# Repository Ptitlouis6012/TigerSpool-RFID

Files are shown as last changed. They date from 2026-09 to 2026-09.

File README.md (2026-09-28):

<p align="center">
  <picture>
    <source media="(prefers-color-scheme: dark)"  srcset="assets/logo-tigertag-head-dark.svg">
    <source media="(prefers-color-scheme: light)" srcset="assets/logo-tigertag-head.svg">
    TigerTag
  </picture>
</p>

<h1 align="center">TigerSpool RFID</h1>

<p align="center">
  <strong>Tap a spool on the box. The filament lands in the right printer slot.</strong><br>
  A 2.0" touchscreen, a PN532 reader, and no typing.
</p>

<p align="center">
  
  
  
  
  
</p>

<p align="center">
  <a href="https://tigertag-project.github.io/TigerSpool-RFID/">
    Install TigerSpool from your browser
  </a>
</p>

<p align="center">
  <a href="#what-it-is">What it is</a>
  &nbsp;&middot;&nbsp;
  <a href="#the-case-a-desktop-stand-or-built-into-your-printer">Print the case</a>
  &nbsp;&middot;&nbsp;
  <a href="#before-you-start">Before you start</a>
  &nbsp;&middot;&nbsp;
  <a href="#quick-start">Quick start</a>
  &nbsp;&middot;&nbsp;
  <a href="#build-it-yourself">Build one</a>
</p>

<p align="center">
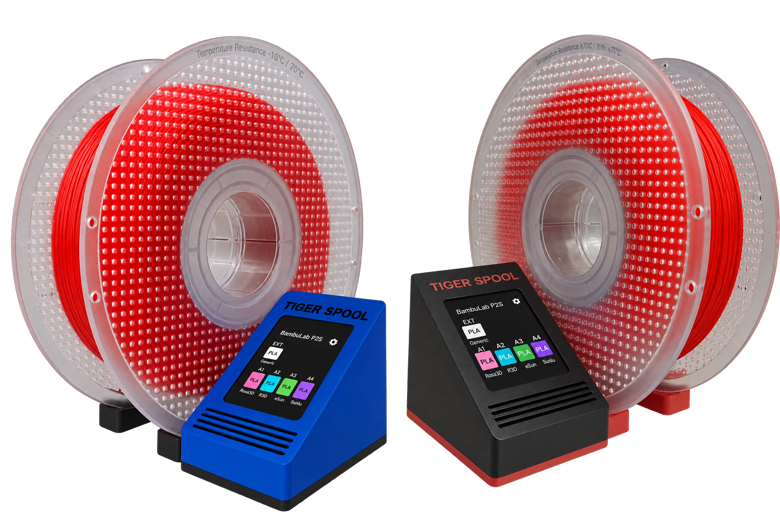
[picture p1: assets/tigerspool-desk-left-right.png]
Two TigerSpool desktop stands side by side: spool on the left, and spool on the right
  
</p>

---

**TigerSpool RFID** is open-source firmware for a small box that sits next to
your 3D printer. Hold a spool carrying a TigerTag NFC chip against it, pick a
slot on the touchscreen, and the box writes the filament into that slot on the
printer — material, brand, colour and temperatures. No app, no keyboard, no
retyping what the tag already knows.

MIT licensed. Built with PlatformIO for the ESP32-S3.

---

## What it is

Your printer already has a slot list. Your filament already carries its own
identity. TigerSpool is the thirty centimetres between them.

<p align="center">
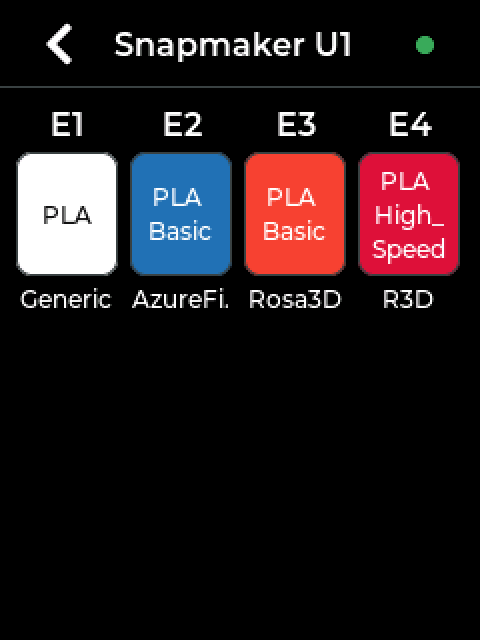
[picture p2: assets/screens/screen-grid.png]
A printer's slots on the TigerSpool screen
  
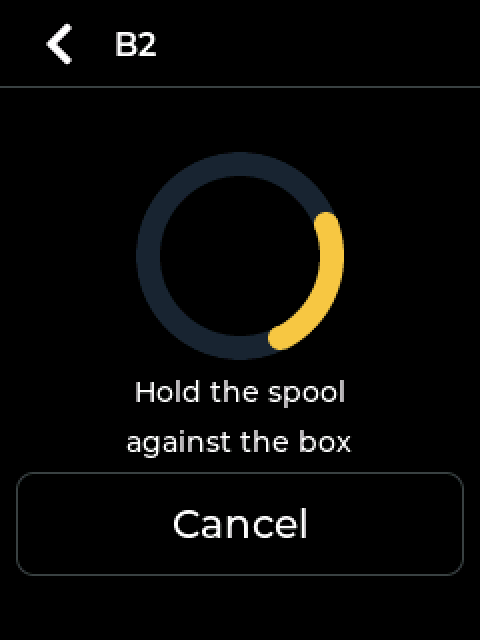
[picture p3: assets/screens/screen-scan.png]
Hold the spool against the box
  
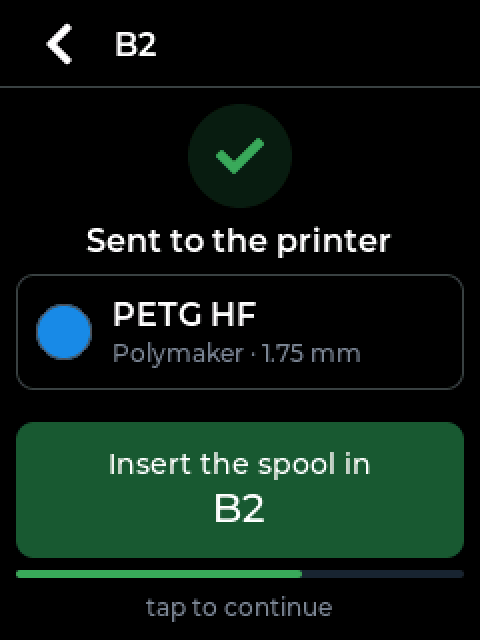
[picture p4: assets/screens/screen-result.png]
Sent to the printer: insert the spool in its slot
  
</p>

<p align="center">
  <sub>1. Tap a slot · 2. Hold the spool against the box · 3. Sent - load it where the box says.</sub>
</p>

- **Tap a slot, present the spool, done.** There is nothing to confirm: the
  assignment leaves for the printer as soon as the tag is read, over the
  printer's own protocol, and the box tells you which slot to load.
- **Scan mode: what is this spool?** Put one on the reader and the box shows
  what the chip holds - colour, material, brand, the two temperature windows,
  the drying instruction, what is left on it, and whether the tag is certified.
  No printer involved.
- **Your printers come from your account.** They are configured once, in Tiger
  Studio Manager, and every TigerSpool you own reads the same list.
- **It speaks nine languages** - English, French, German, Spanish, Italian,
  Polish, both Portuguese and Chinese - and asks which one before anything else.
- **It updates itself.** Over the air, verified, from this repository's releases.

## The case: a desktop stand, or built into your printer

**The desktop stand is TigerSpool.** It stands beside any printer, holds the
spool against the reader while you tap, and is the one to print if you are not
sure. It comes in two mirrored versions, the spool on the left of the screen or
on the right. No screws, no inserts: it is 100 % printed, and it prints without
supports.

<div align="center">

| Spool on the left | Spool on the right |
|---|---|
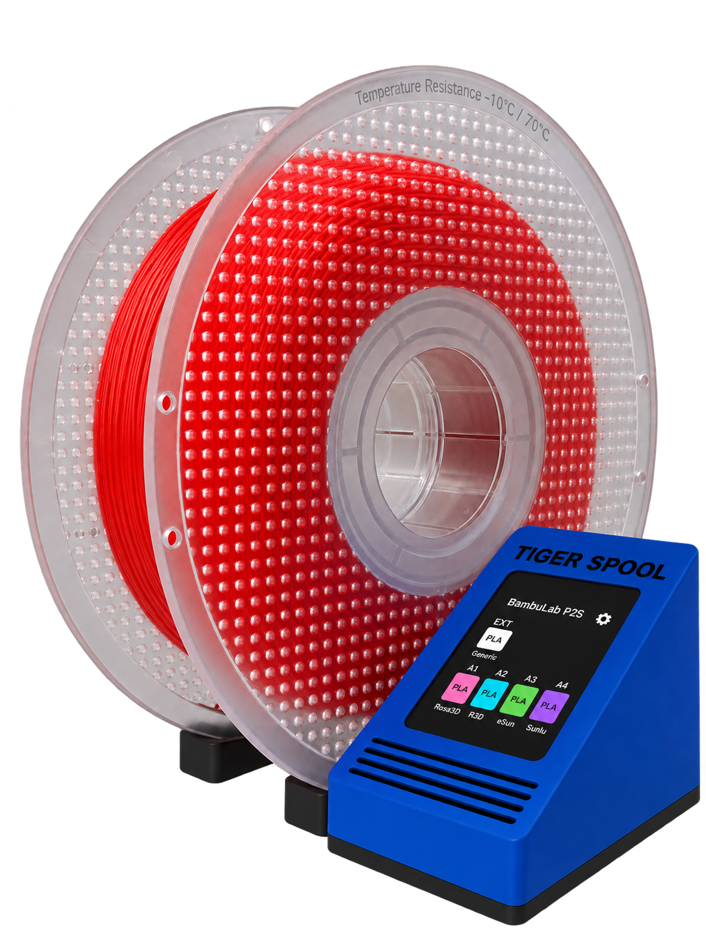
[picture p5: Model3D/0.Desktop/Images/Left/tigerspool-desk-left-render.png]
The desktop stand, spool on the left
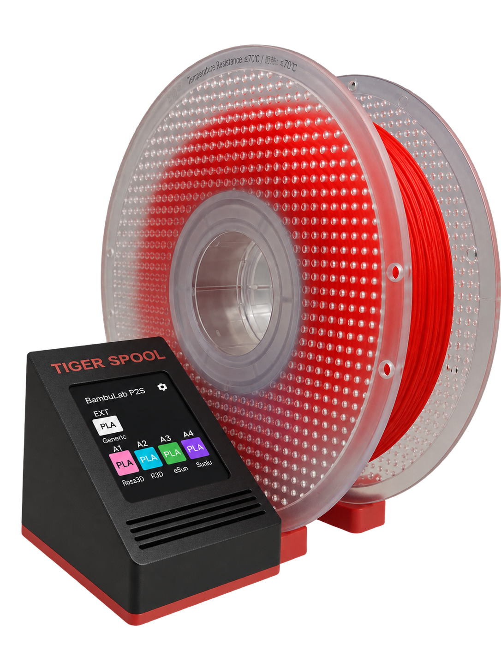
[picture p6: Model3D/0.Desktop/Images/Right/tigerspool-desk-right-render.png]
The desktop stand, spool on the right
|  |  |
| **[Print it from MakerWorld](https://makerworld.com/models/3360492-tigerspool-desktop-stand-spool-on-the-left)** · [files](Model3D/0.Desktop/) | **[Print it from MakerWorld](https://makerworld.com/models/3360619-tigerspool-desktop-stand-spool-on-the-right)** · [files](Model3D/0.Desktop/) |

</div>

**The printer integrations** are the same TigerSpool - same board, same reader,
same firmware - in a shell that clips onto a printer's own screen, so the box
lives where the spools are loaded.

<div align="center">

| Printer | | Print it |
|---|---|---|
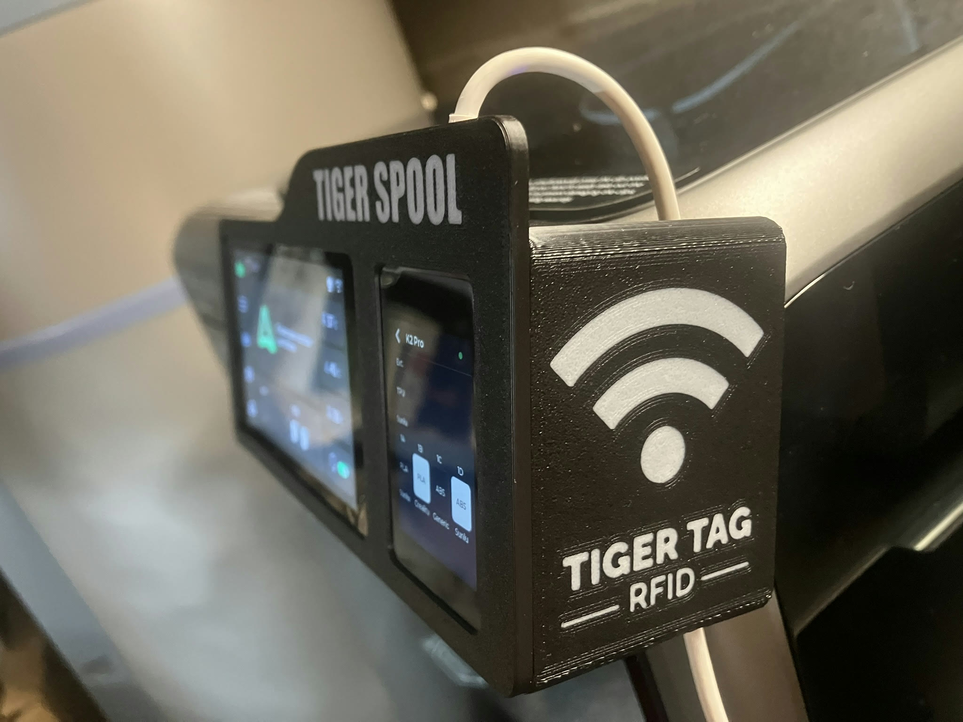
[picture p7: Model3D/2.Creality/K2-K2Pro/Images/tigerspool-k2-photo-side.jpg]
TigerSpool on a K2 Pro, the RFID reader and its logo on the side
| **Creality K2**<br>**Creality K2 Pro** |  | **[MakerWorld](https://makerworld.com/models/3361291-tigerspool-for-creality-k2-and-k2-pro)** · [files](Model3D/2.Creality/K2-K2Pro/) |
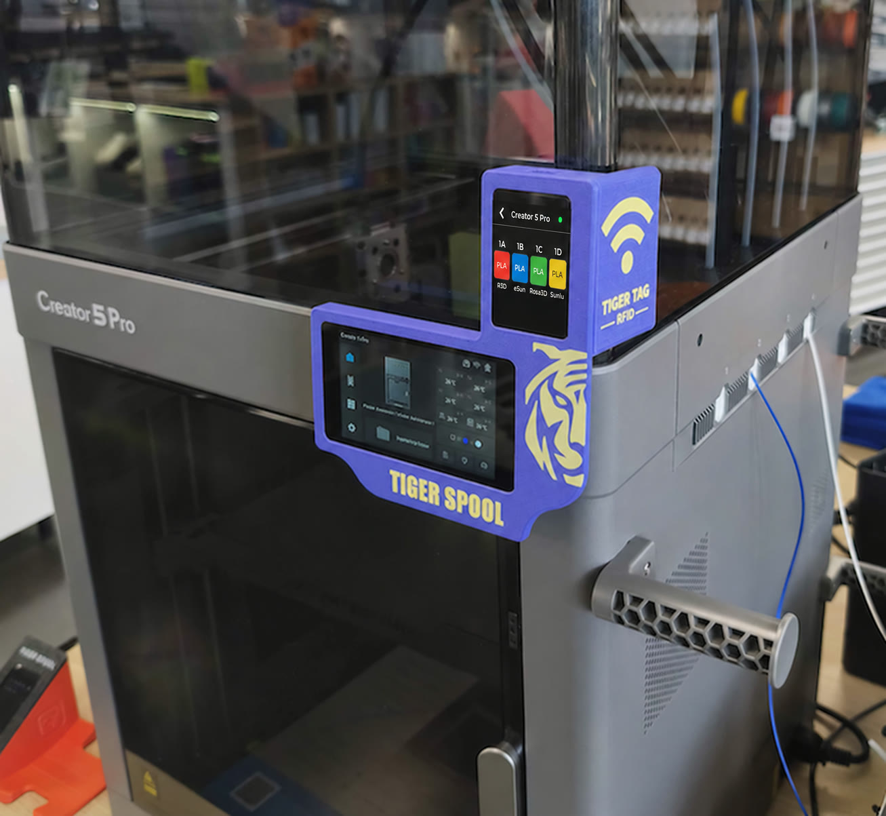
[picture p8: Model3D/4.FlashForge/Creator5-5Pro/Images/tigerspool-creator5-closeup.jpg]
TigerSpool clipped onto a Creator 5 Pro, its screen on and the RFID logo on the side
| **FlashForge Creator 5**<br>**FlashForge Creator 5 Pro** |  | **[MakerWorld](https://makerworld.com/models/3361301-tigerspool-rfid-for-flashforge-creator-5-and-5-pro)** · [files](Model3D/4.FlashForge/Creator5-5Pro/)<br><br>**[Firmware "FlashForge × TigerTag"](https://tigertag-project.github.io/FlashForge-TigerTag-Creator5-Firmware-Lan-and-Cloud/download/creator5/)**<br>LAN + Cloud<br>Recommended |
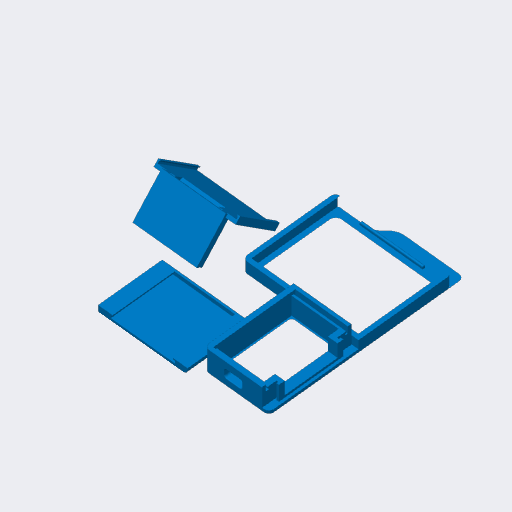
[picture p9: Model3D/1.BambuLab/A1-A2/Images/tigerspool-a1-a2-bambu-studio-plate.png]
The A1 and A2L case on the slicer plate
| **Bambu Lab A1**<br>**Bambu Lab A2L** |  | [files](Model3D/1.BambuLab/A1-A2/) - not on MakerWorld yet |
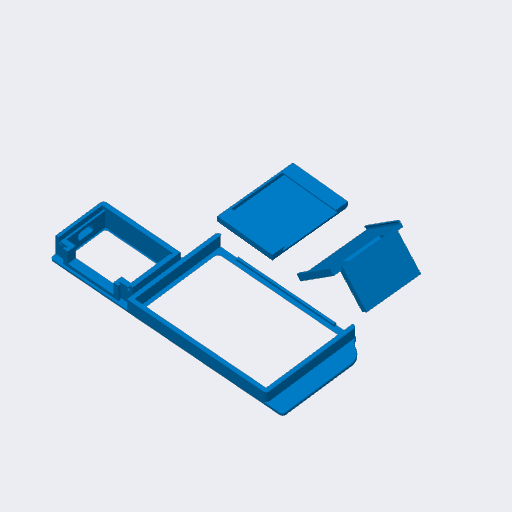
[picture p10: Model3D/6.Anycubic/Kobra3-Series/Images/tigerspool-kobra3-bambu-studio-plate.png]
The Kobra 3 case on the slicer plate
| **Anycubic Kobra 3**<br>**Anycubic Kobra 3 V2**<br>**Anycubic Kobra 3 Max**<br>**Anycubic Kobra 3 Max V2** |  | [files](Model3D/6.Anycubic/Kobra3-Series/) - not on MakerWorld yet |

</div>

Every model, its print settings and how to add one: **[Model3D/](Model3D/)**.

## Before you start

**This is the part that catches people out, so it is first.**

A TigerSpool has no keyboard and no way to type a printer's address, and that is
deliberate — it reads your printers from your TigerTag account instead. Which
means two things have to exist before the box is useful:

### 1. A TigerTag account, created in Tiger Studio Manager

**[Tiger Studio Manager](https://github.com/TigerTag-Project/TigerTag-Studio-Manager)**
is the desktop application for the ecosystem. Install it and create an account
there. That account is what the TigerSpool signs in to — by e-mail, or with
Google through a QR code, so you never type a password on a 2" screen.

Without an account, the box gets through Wi-Fi setup and then has nothing to
sign in to.

<p align="center">
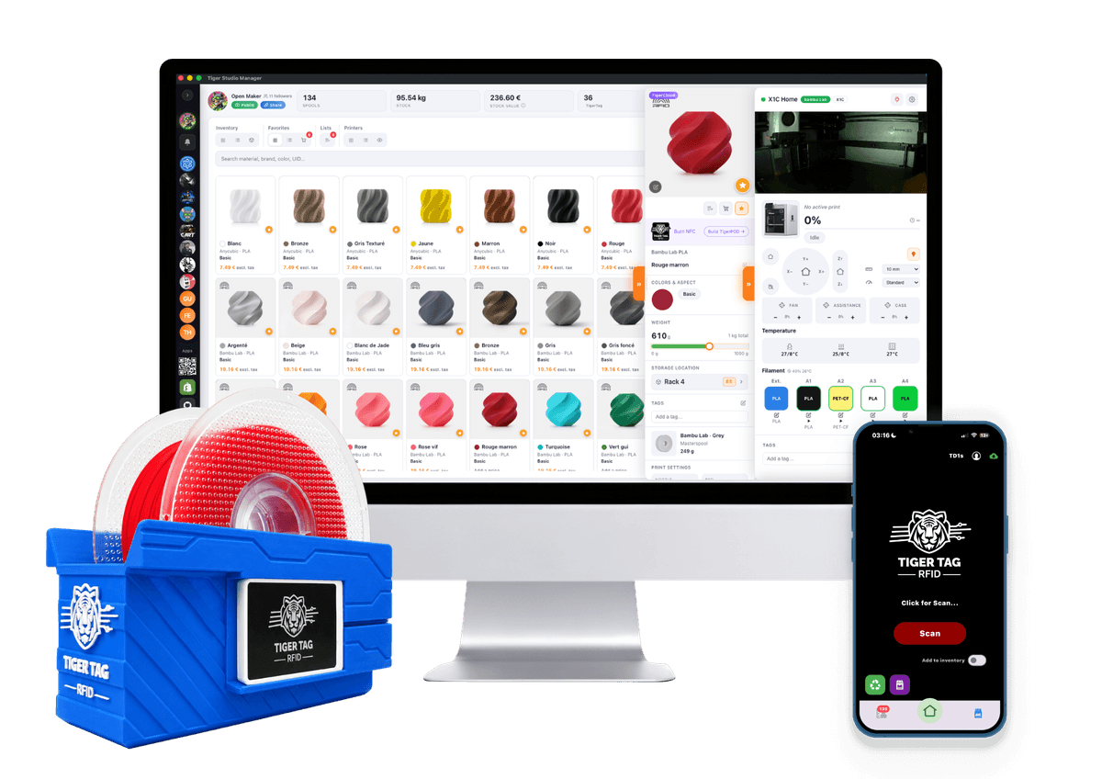
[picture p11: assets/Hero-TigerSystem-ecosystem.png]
The TigerTag system: a TigerPOD reader, Tiger Studio Manager on a desktop, and the TigerTag app on a phone
  
</p>

<p align="center">
  <sub>The TigerTag system: one account, shared by Tiger Studio Manager, the
  TigerTag app and every device - TigerSpool included.</sub>
</p>

### 2. Your printers, added in Tiger Studio Manager

Adding a printer means Tiger Studio finds it on your network, or you enter its
address and access code, and stores it against your account.

**If you have not done this, the printer list on the box will be empty.** That is
not a fault and there is nothing to fix on the device — it is showing you exactly
what your account contains. Add the printer in Tiger Studio, and it appears on
the box at the next sync.

The same is true for the details: the access code, the IP address, the brand and
model all come from there. TigerSpool reads that list; it does not build it.

<p align="center">
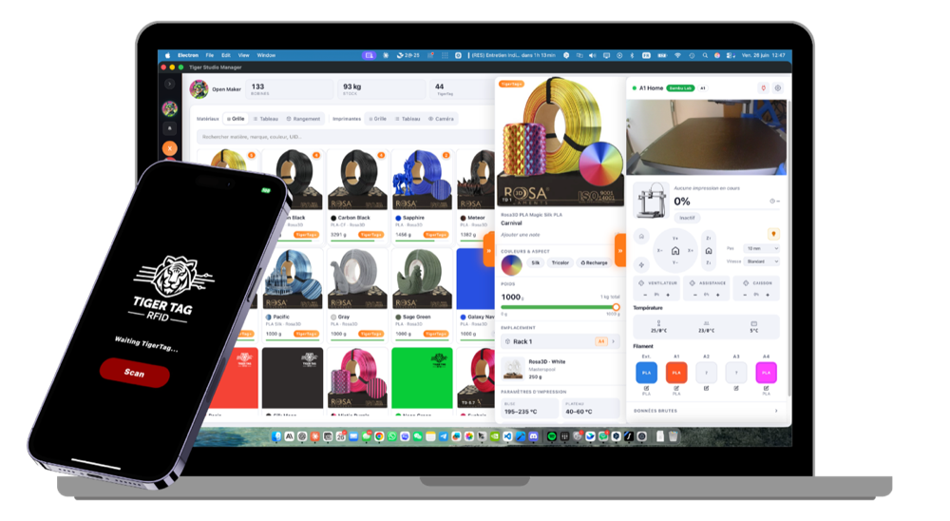
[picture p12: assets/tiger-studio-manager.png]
Tiger Studio Manager showing a filament library and a printer's slots
  
</p>

<p align="center">
  <sub>Tiger Studio Manager. Your filaments and your printers live here — the box
  reads this list, it does not build it.</sub>
</p>

> **In short:** Tiger Studio Manager → create an account → add your printers →
> *then* set up the box.

## Quick start

### Step 1 — install from your browser

**Plug the board into your computer → click Install → wait a minute.** Use the
button at the top of this page. It writes the bootloader, the partition table,
the boot selector and the firmware.

Chrome, Edge or Opera, on a desktop or laptop. Safari and Firefox do not
implement WebSerial and no mobile browser does — the page says so rather than
failing quietly.

### Step 2 — set it up on the box

1. **Pick your language.** Nine of them, before anything else.
2. **Join Wi-Fi.** The box shows a QR code. Scan it with your phone, and a page
   opens listing the networks it can see. Pick yours, type the password on your
   phone, and the box joins — no reboot, nothing typed on the small screen.
3. **Sign in.** E-mail and password, or Google through a second QR code.
4. **Your printers arrive.** From your account, as configured in Tiger Studio.
   The box's address on your network (`http://tigerspool-xxxx.local/`) shows
   who is signed in, lists those printers with a switch for each, syncs them
   again, and signs out - all from a phone.

<p align="center">
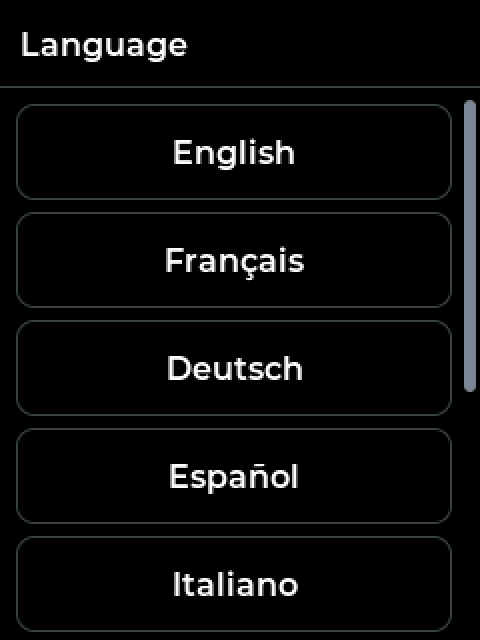
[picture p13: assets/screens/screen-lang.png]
Pick your language
  
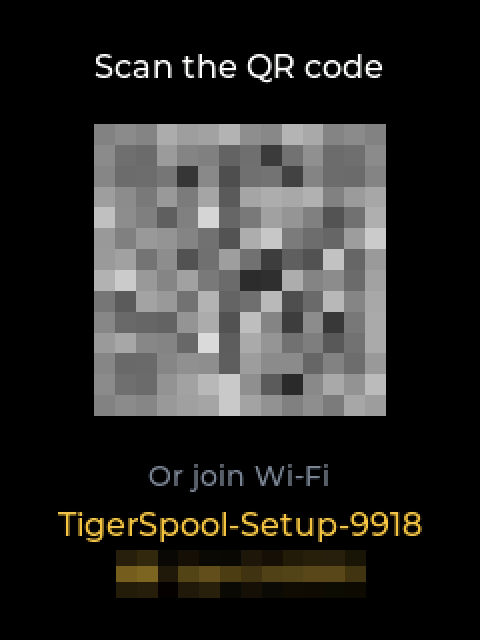
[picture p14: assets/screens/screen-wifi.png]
Join Wi-Fi from your phone by scanning a QR code
  
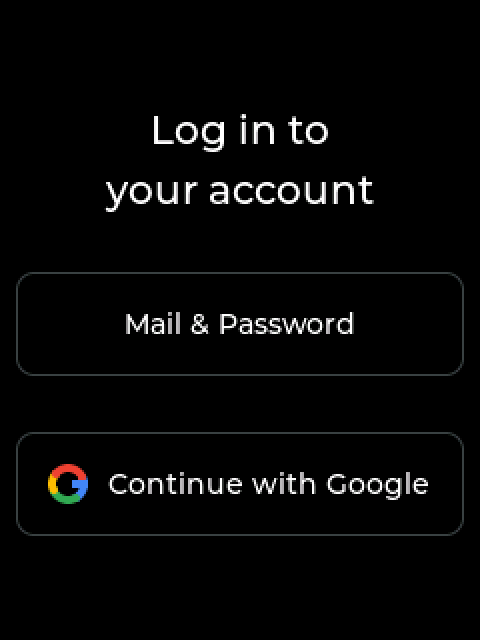
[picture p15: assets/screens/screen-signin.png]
Sign in to your TigerTag account
  
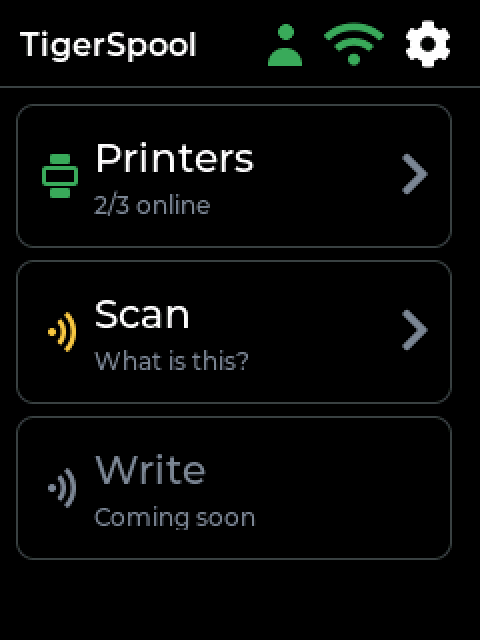
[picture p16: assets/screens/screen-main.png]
Ready: your printers, from your account
  
</p>

Then tap the slot you want and hold a tagged spool against the box. It is sent
to the printer as soon as it is read - there is nothing to confirm - and the
box then tells you where to put it.

That last part is the one people miss: **it tells the printer what the spool
is, it does not load it.** Putting the spool in that slot - the CFS, the AMS,
the ACE unit, whatever your printer calls its tray - is still yours to do.

From then on it updates itself over the air.

### Build it yourself

```bash
git clone https://github.com/TigerTag-Project/TigerSpool-RFID.git
cd TigerSpool-RFID

bash scripts/flash.sh --monitor
```

That builds the firmware, flashes it over USB and opens the serial console.
Requires [PlatformIO Core](https://docs.platformio.org/en/latest/core/installation/).

An ordinary flash **keeps your Wi-Fi credentials, your account session and your
printers** — nothing it writes touches the NVS partition. `--erase` wipes the
chip and is how you get a genuine first-boot again.

## Hardware

One board, one reader, four wires. The electronics are identical for every
printer brand — only the 3D-printed shell changes.

<div align="center">

| Qty | Component | Link |
|---|---|---|
| 1 | Waveshare ESP32-S3-Touch-LCD-2 — 240×320 IPS touch, ESP32-S3**R8**, 16 MB flash, 8 MB octal PSRAM. Screen, touch and MCU on one board | [buy](https://link.amazon/B06RoLfDi) |
| 1 | PN532 **V3** NFC module — DIP switches, set to **HSU (UART)**: both switches `0` / OFF, not I²C, not SPI | [buy](https://link.amazon/B0iJgHVtP) |
| 1 | USB-C to USB-A cable **that carries data** — a charge-only cable makes a working board look dead: no serial port ever appears | [buy](https://link.amazon/B00Xg3WT4) |
| — | Four jumper wires — 3V3, GND, TX, RX | ships with the PN532 |
| 1 | 3D-printed case — the desktop stand, or the integration made for your printer ([above](#the-case-a-desktop-stand-or-built-into-your-printer)) | [MakerWorld](https://makerworld.com/@TigerTag) · [Model3D/](Model3D/) |
| *opt.* | Magnetic USB connector — the port is the one part handled every day; the cable lets go instead of the socket | [buy](https://link.amazon/B0bWVIBa0) |
| *opt.* | 3.7 V 1000 mAh LiPo cell, PH1.25 — charged over USB, and the box runs from it with the cable out. Optional: declare it in **Settings › Battery**, since the board cannot detect it. **Check the polarity** | [buy](https://link.amazon/B0fL0jjf3) |

</div>

**About 40 €** in total, plus filament.

> Some of the links above are Amazon affiliate links: buying through them pays
> the project a small commission at no cost to you. Nothing on this list is
> chosen because it is affiliated — any equivalent module works.

Full parts list: **[hardware/BOM.md](hardware/BOM.md)** ·
Wiring: **[docs/WIRING.md](docs/WIRING.md)** and **[hardware/pinout.md](hardware/pinout.md)**

<p align="center">
  <a href="docs/WIRING.md">
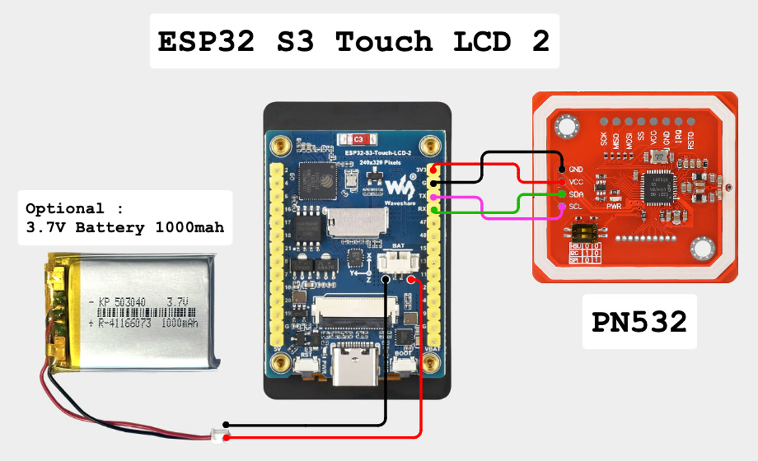
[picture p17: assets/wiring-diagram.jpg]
Wiring diagram: ESP32-S3-Touch-LCD-2 to PN532 — 3V3 to VCC, G to GND, TX to SCL, RX to SDA, and the optional 3.7 V battery on the BAT connector
    
  </a>
</p>
<p align="center">
  <sub><a href="https://app.cirkitdesigner.com/project/5b546f4e-70b8-4735-afff-be6bd36bc10c">Interactive schematic in Cirkit Designer</a></sub>
</p>

> **The reader goes on GPIO43/44.** Not GPIO6/7 — that pair is an I²C bus with
> pull-ups on this board. A PN532 wired there powers up, answers, and returns
> random UIDs with failing reads. It looks like a bad tag or a bad antenna. It is
> neither, and it costs a day. Follow [docs/WIRING.md](docs/WIRING.md) exactly.

## Printer support

**Every printer Tiger Studio Manager can add works with TigerSpool** - the
models below are that list. The current state of
every brand is in **[docs/PRINTER-COMPATIBILITY.md](docs/PRINTER-COMPATIBILITY.md)**,
which grades each on three levels — ✅ automatic, ⚙️ one setup step,
🧪 experimental. Read it before buying parts for a specific printer.

<div align="center">

| Brand | Firmware support | Transport |
|---|---|---|
| **Creality** | ✅ implemented, proven on hardware | WebSocket |
| **FlashForge** | ✅ implemented, proven on hardware | HTTP |
| **Bambu Lab** | ✅ implemented, proven on hardware - LAN and cloud mode | MQTT over TLS |
| **Snapmaker** | ✅ implemented, proven on hardware | Moonraker over WebSocket |
| **Elegoo** | ✅ implemented, reading proven on hardware | MQTT |
| **Anycubic** | ✅ implemented, proven on hardware - LAN and cloud mode | MQTT over TLS |

</div>

**How TigerSpool reaches each printer, and what to switch on first.** A
**Combo** is the same printer with its AMS, CFS, ACE or CANVAS attached, and
works the same way.

<div align="center">

| Printer | Mode | What to do on the printer |
|---|:---:|---|
| **Bambu Lab**<br>Bambu Lab A1 mini<br>Bambu Lab A1<br>Bambu Lab A2L<br>Bambu Lab P1P<br>Bambu Lab P1S<br>Bambu Lab P2S<br>Bambu Lab X1C<br>Bambu Lab X1E<br>Bambu Lab X2D<br>Bambu Lab H2D<br>Bambu Lab H2D Pro<br>Bambu Lab H2S<br>Bambu Lab H2C | LAN<br>Cloud, read only | LAN: turn on **LAN mode and Developer mode** on the printer. Cloud: nothing on the printer - the spools are shown, but a tag cannot be written to the slot. |
| **Creality**<br>Creality K1<br>Creality K1C<br>Creality K1 SE<br>Creality K1 Max<br>Creality K2<br>Creality K2 SE<br>Creality K2 Pro<br>Creality K2 Plus<br>Creality Hi<br>Creality Ender-3 V4<br>Creality SparkX i7 | LAN | Nothing: the printer accepts local requests while it stays on Creality Cloud. |
| **FlashForge**<br>FlashForge Creator 5<br>FlashForge Creator 5 Pro | LAN | Either turn **LAN mode** on - which disconnects FlashForge Cloud - or install the [FlashForge × TigerTag firmware](https://tigertag-project.github.io/FlashForge-TigerTag-Creator5-Firmware-Lan-and-Cloud/download/creator5/), which keeps LAN and Cloud on together. |
| **FlashForge**<br>FlashForge AD5X<br>FlashForge Adventurer 5M<br>FlashForge Adventurer 5M Pro<br>FlashForge A5 | LAN | Turn **LAN mode** on. It disconnects FlashForge Cloud. |
| **Anycubic**<br>Anycubic Kobra 3<br>Anycubic Kobra 3 V2<br>Anycubic Kobra 3 Max<br>Anycubic Kobra 3 Max V2<br>Anycubic Kobra S1<br>Anycubic Kobra X | LAN<br>Cloud | Your choice. **LAN mode**: pair the printer once in AnycubicSlicerNext - its credentials come from there, through Tiger Studio. **Anycubic Cloud**: add it to Tiger Studio in cloud mode; TigerSpool connects beside Tiger Studio without taking its place. |
| **Elegoo**<br>Elegoo Centauri 2<br>Elegoo Centauri 2 Combo<br>Elegoo Centauri Carbon 2<br>Elegoo Centauri Carbon 2 Combo | LAN | Nothing: the access code comes from your account. |
| **Snapmaker**<br>Snapmaker U1 | LAN | Nothing. |

</div>

A Bambu Lab printer in **cloud mode** is read-only: its spools are shown, but a
tag cannot be written to it - Bambu's cloud does not accept the command. Switch
the printer to LAN mode to write.

Slot names match the ones the printer and Tiger Studio use — `Ext.` plus
`1A`–`1D` on Creality and FlashForge, `A1`–`A4` then `B1`–`B4` on Bambu,
`E1`–`E4` on Snapmaker, `S1`–`S4` on Elegoo, `A1`–`A4` per ACE unit on
Anycubic. An Elegoo **Combo** has the CANVAS unit and its four colours,
`S1`–`S4`; a Centauri without it has the single `Ext.` slot. The table and its two traps are in the compatibility document.

## How many printers at once

**The limit is not a number of printers - it is how much memory their
connections take.** One TigerSpool has a fixed budget of **160 load slots**,
where one load slot is one kilobyte of the chip's internal RAM, and each printer
takes what its connection costs:

<div align="center">

| Printer | Load slots |
|---|---|
| First Bambu Lab in cloud mode | 50 |
| Each further Bambu Lab in cloud mode | 4 - they share one connection |
| Bambu Lab in LAN mode | 50 |
| Anycubic in LAN mode | 41 |
| First Anycubic in cloud mode | 50 |
| Each further Anycubic in cloud mode | 4 - they share one connection |
| Creality | 6 |
| Snapmaker | 5 |
| Elegoo | 3 |
| FlashForge | 2 |

</div>

The difference is encryption: a Bambu or an Anycubic talks over TLS, which is
what memory goes on; the others do not. So ten Elegoos fit where three LAN
Bambus do not.

**Settings > Printers** shows how full the budget is as a percentage. A printer
that would not fit is refused when you switch it on, with the reason on the
screen, rather than connecting and failing later. The measurements, the reasons
for 160, and what the budget does not account for are in
**[docs/CONNECTION-BUDGET.md](docs/CONNECTION-BUDGET.md)**.

## Documentation

<div align="center">

| | |
|---|---|
| [ARCHITECTURE.md](docs/ARCHITECTURE.md) | Layering, the state machine, why a backend knows nothing about the screen |
| [ONBOARDING.md](docs/ONBOARDING.md) | The first-boot journey, screen by screen |
| [WIFI-PROVISIONING.md](docs/WIFI-PROVISIONING.md) | The QR code and the captive portal |
| [ACCOUNT-PAIRING.md](docs/ACCOUNT-PAIRING.md) | E-mail and Google sign-in, and why RFC 8628 was rejected |
| [ACCOUNT-DATA.md](docs/ACCOUNT-DATA.md) | The shape a printer arrives in |
| [OTA.md](docs/OTA.md) | Partitions, the manifest, and what is settled before the first release |
| [PRINTER-COMPATIBILITY.md](docs/PRINTER-COMPATIBILITY.md) | Per-brand status and slot naming |
| [CONNECTION-BUDGET.md](docs/CONNECTION-BUDGET.md) | How many printers at once: load slots, every measurement behind them, why 160 |
| [PRESENCE.md](docs/PRESENCE.md) | How a box declares itself to the account, so Tiger Studio can list it |
| [WIRING.md](docs/WIRING.md) | The four wires |
| [ROADMAP.md](docs/ROADMAP.md) | What is deliberately not done yet, and what has to be decided first |

</div>

Contributors and agents start at **[AGENTS.md](AGENTS.md)** and
**[CODEMAP.md](CODEMAP.md)**.

## Known limitations

Written down rather than discovered.

- **The firmware is not signed.** Its update connection is verified against the
  root certificate store, so the box knows who it is talking to — but not who
  produced the image. The reasoning and the condition for changing that are in
  [docs/OTA.md](docs/OTA.md).
- **At most three printers that use TLS at once** - Bambu Lab in LAN mode and
  Anycubic, with every cloud Bambu on an account counting as one and every
  cloud Anycubic as one more. It is the
  chip's internal RAM, and the load budget enforces it; see
  [docs/CONNECTION-BUDGET.md](docs/CONNECTION-BUDGET.md). The two ways past it
  are in [docs/ROADMAP.md](docs/ROADMAP.md).
- **A battery has to be declared, in Settings.** The board has no way to tell
  whether a cell is on its connector - no sense line, and the two indirect
  signals were each measured wrong on real hardware - so it asks instead of
  guessing. Until someone answers, it reports no battery.
- **A printer is identified by its position in your account's list.** Reordering
  it in Tiger Studio can move a per-printer setting to the wrong machine. Tracked
  in [docs/reviews/](docs/reviews/).

## Part of the TigerTag ecosystem

TigerTag is an open NFC identification standard for 3D-printing materials. A
spool carries its own identity, and every device in the system reads the same
one.

- **[Tiger Studio Manager](https://github.com/TigerTag-Project/TigerTag-Studio-Manager)** — desktop printer and filament manager. **Start here**: it is where an account is created and printers are declared.
- **[TigerTag-RFID-Guide](https://github.com/TigerTag-Project/TigerTag-RFID-Guide)** — the protocol specification and public registry
- **[TigerSystem-Docs](https://github.com/TigerTag-Project/TigerSystem-Docs)** — ecosystem source of truth
- **[Tiger-Scale-V3](https://github.com/TigerTag-Project/Tiger-Scale-V3)** — the connected filament scale
- **[TigerPOD](https://github.com/TigerTag-Project/TigerPOD)** — open desktop NFC reader/writer
- **SDKs** — [Python](https://github.com/TigerTag-Project/TigerTag-SDK-Python) · [JavaScript](https://github.com/TigerTag-Project/TigerTag-SDK-JS)

## Contributing

Issues and pull requests are welcome. [CONTRIBUTING.md](CONTRIBUTING.md) has the
conventions; the short version is that `bash scripts/verify.sh` passes before
anything is reported as done, and everything committed is in English.

Security reports: [SECURITY.md](SECURITY.md).

## License

[MIT](LICENSE) — build it, sell it, fork it.

Third-party components keep their own licenses; see
[THIRD_PARTY_LICENSES.md](THIRD_PARTY_LICENSES.md). "TigerTag" and "TigerSpool"
are project names, not a license to imply endorsement — the terms for using them
on a product you sell are in [TRADEMARK.md](TRADEMARK.md).

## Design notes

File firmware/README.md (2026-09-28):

# firmware/

The TigerSpool firmware: one PlatformIO project for the Waveshare
ESP32-S3-Touch-LCD-2 with a PN532 reader. `tigerspool` is the build CI makes and
releases; `tigerspool-bench` is the same plus the diagnostics kept inside
`#if TIGERSPOOL_BENCH` (`src/bench.h`), and is never released.

## Layout

```
firmware/
├── platformio.ini          env: tigerspool
├── partitions.csv          two OTA slots, frozen - docs/OTA.md
├── include/                board and LVGL configuration, generated headers
│   ├── version.h           TIGERSPOOL_FW_VERSION, the one version macro
│   └── tigertag_db.h       generated from tools/tigertag_db - never hand-edited
├── lib/
│   └── PN532/              vendored reader driver - ONE copy, patches documented
├── tools/tigertag_db/      mirror of the public TigerTag reference tables
└── src/
    ├── main.cpp            the state machine and the only writable device state
    ├── printer.h           the backend interface and the printer record
    ├── printer_budget.h    how many printers at once - docs/CONNECTION-BUDGET.md
    ├── backend_*.cpp       one backend per brand, one object per printer
    ├── bambu_cloud.cpp     the TLS session every cloud Bambu on an account shares
    ├── filament_resolve.cpp what a slot is sent, field by field - pure, host-testable
    ├── product_api.cpp     the TigerTag+ product lookup, on its own task
    ├── reader.cpp          PN532 use, TigerTag decoding
    ├── battery.cpp         the cell on the boards that have one - GPIO5
    ├── tigertag_cloud.cpp  account sign-in, pairing, printer import
    ├── tt_db.cpp           reference-table lookups, compiled and downloaded
    ├── webcfg.cpp          captive portal, LAN page, /screen.bmp, /api/*
    ├── i18n.cpp            every on-screen string, in nine languages
    ├── net/                captive DNS, OTA, TLS helpers
    └── ui/                 LVGL screens, theme, icons, generated fonts
```

What each file owns, what it must not be asked to do, and the landmines to read
before editing it are in [../CODEMAP.md](../CODEMAP.md). This tree is the
overview; the map is the reference.

## Rules for this tree

**No credentials, ever.** Not Wi-Fi, not printer access codes, not API keys with
authority. Everything comes from NVS at runtime. The published binary is the same
for every user. See [../SECURITY.md](../SECURITY.md).

**One copy of the vendored library.** The prototype carries three, which have
already drifted into different behaviour —
[../docs/MIGRATION.md](../docs/MIGRATION.md#the-vendored-pn532-library). Patches
to a vendored library carry a comment saying what breaks without them.

**English only.** Comments, identifiers, log messages, commit messages.
User-facing strings go through the i18n layer (`i18n.cpp`), in every language
at once.

**Hardware facts get a comment explaining why.** Every constant that looks
arbitrary — a delay, a page range, a retry count — is arbitrary-looking because
it was expensive to find. Say what breaks if it changes.

## Build

```bash
pio run -e tigerspool                 # compile
bash ../scripts/flash.sh --monitor    # build, flash over USB, open the console
bash ../scripts/verify.sh             # the guards CI runs, plus a build
```

`flash.sh` checks the board's MAC before writing, so it cannot flash the wrong
device on a bench with several plugged in.

Most users will never do this — they install from the browser, and after that
the device updates itself over the air ([../docs/OTA.md](../docs/OTA.md)).

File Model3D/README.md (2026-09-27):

# 3D-printable cases

**The [desktop stand](0.Desktop/) is the base model.** It stands beside any
printer, and it is the one to print if you are not sure. Every other model is a
**printer integration**: the same TigerSpool in a shell that clips onto one
printer's own screen.

<p align="center">
  The desktop stand, spool on the left and spool on the right
</p>

| Model | Kind | MakerWorld | Files |
|---|---|---|---|
| Desktop stand, spool on the left | base, any printer | [print it](https://makerworld.com/models/3360492-tigerspool-desktop-stand-spool-on-the-left) | [`0.Desktop/`](0.Desktop/) |
| Desktop stand, spool on the right | base, any printer | [print it](https://makerworld.com/models/3360619-tigerspool-desktop-stand-spool-on-the-right) | [`0.Desktop/`](0.Desktop/) |
| Creality K2, K2 Pro | integration, clips onto the screen | [print it](https://makerworld.com/models/3361291-tigerspool-for-creality-k2-and-k2-pro) | [`2.Creality/K2-K2Pro/`](2.Creality/K2-K2Pro/) |
| FlashForge Creator 5, 5 Pro | integration, clips onto the screen | [print it](https://makerworld.com/models/3361301-tigerspool-rfid-for-flashforge-creator-5-and-5-pro) | [`4.FlashForge/Creator5-5Pro/`](4.FlashForge/Creator5-5Pro/) |
| Bambu Lab A1, A2L | integration, clips onto the screen | not yet | [`1.BambuLab/A1-A2/`](1.BambuLab/A1-A2/) |
| Anycubic Kobra 3, every model | integration, clips onto the screen | not yet | [`6.Anycubic/Kobra3-Series/`](6.Anycubic/Kobra3-Series/) |

Each brand directory lists its models. On MakerWorld every page carries the
full Bambu Studio project and the whole build guide; the bare parts, the other
slicers' projects and the Fusion sources are here.

---

## The rule that governs every model in this directory

**Only the shell changes. The electronics, the wiring and the connectors are
strictly identical across every model.**

Same Waveshare ESP32-S3-Touch-LCD-2. Same PN532. Same four wires on the same pins.
Same USB-C entry. A TigerSpool built for a Bambu Lab and one built for a Creality
are the same device in a different jacket, and either firmware image runs on
either one.

This is not a convention. It is what makes the project shippable:

- **One firmware.** No per-model build, no variant to pick in the installer, no
  way to flash the wrong image.
- **One bill of materials.** [../hardware/BOM.md](../hardware/BOM.md) is complete
  for every model.
- **One set of wiring instructions.** [../docs/WIRING.md](../docs/WIRING.md)
  is correct for every model.
- **Anyone can add a model** without touching a line of code.

A design that needs a different board, a different reader, extra components, or a
change to the pinout **is not a TigerSpool model**. It is a fork, and it is
welcome as one — under a different name.

---

## What each model has to do

Different only in how it mounts. Every one of them has to:

| Requirement | Why |
|---|---|
| Hold the PN532 antenna **2–4 cm** from where a spool naturally rests | That is the reader's entire range ([../docs/WIRING.md](../docs/WIRING.md)) |
| Keep the antenna **away from the display's metal back** and any ground plane | Both destroy what little range there is |
| Present the 2.0" screen at a readable, tappable angle | It is a touchscreen, used standing up |
| Leave the USB-C port reachable | Power, and recovery flashing |
| Print without supports where possible, and on a printer of the brand it is for | It is a case for that printer; it should print on it |
| Say clearly **where to hold the spool** | Moulded, embossed, or an obvious surface — not in a manual |

---

## Directory layout

```
Model3D/
├── TEMPLATE.md                the README every model starts from
├── 0.Desktop/                 free-standing, fits any printer - the universal one
├── 1.BambuLab/                one numbered directory per brand ...
│   ├── README.md              ... listing its models
│   └── X1C/                   ... and one directory per printer model
├── 2.Creality/
├── 3.Snapmaker/
├── 4.FlashForge/
├── 5.Elegoo/
└── 6.Anycubic/
```

Two levels, and only two: **brand, then printer model.** A case that fits a
whole range goes in the brand directory under the name of that range (`P1/`
for the P1P and the P1S); one that fits a single machine takes that machine's
name (`K2-Plus/`). A model that fits every printer is not a brand model at all:
it belongs in `0.Desktop/`, or next to it.

**A directory here is about physical mounting, not firmware support.** A case
can be designed for a printer before its network protocol works, so a directory
existing says nothing about whether the device talks to that printer.
[../docs/PRINTER-COMPATIBILITY.md](../docs/PRINTER-COMPATIBILITY.md) is the
authority on what actually works.

### What goes in a model directory

```
K2-Plus/
├── README.md                  from ../TEMPLATE.md
├── Images/                    what it looks like - a photo beats a render
├── Source/                    the editable design: .step, .f3d
├── OriginalFiles/             the parts as exported, one file each, no slicer settings
├── BambuStudio/               one directory per slicer the project is saved from
│   └── *.3mf
└── CrealityPrint/
    └── *.3mf
```

| What | Why |
|---|---|
| `README.md` | Which printers it fits, what to print and in what, how it goes together |
| `Images/` | Nobody downloads a case they cannot see. The slicer's own previews can be taken out of a 3MF (`Metadata/plate_1.png`, `top_1.png`) until there is a photo |
| `Source/` | So the next person can adapt it instead of starting again. `.step` opens everywhere; a native file (`.f3d`) is welcome beside it |
| `OriginalFiles/` | The bare parts, for any slicer and any printer |
| `<Slicer>/*.3mf` | A 3MF saved from a slicer carries the orientation, the supports and the plate for that slicer's printers, and is tied to it. One directory per slicer: `BambuStudio/`, `CrealityPrint/`, `OrcaSlicer/`, `PrusaSlicer/` |

Variants of one design (the desktop stand with the spool on the left or on the
right) are told apart by the file name, or by a `Left/` and `Right/` level where
there are several files per variant.

### Names

**Directories** are written to be read: capitals where they help (`BambuStudio`,
`OriginalFiles`, `K2-Plus`), a number in front of the top-level ones to set
their order. **Files** are lower case with hyphens:
`tigerspool-<model>-<variant>-<part>.3mf`, for example
`tigerspool-desk-left-display-cover.3mf`. **No spaces anywhere**: a space breaks
every link to the path in a README. `scripts/check-models.py` enforces all
three.

### Before a photo is committed

A phone photo records the phone, the time and **the GPS position it was taken
at**. Publish a copy with none of it, scaled to something a page can load:

```bash
ffmpeg -i IMG_1234.jpeg -vf "scale='min(2000,iw)':-2" -map_metadata -1 -q:v 3 \
    Model3D/<Brand>/<Model>/Images/tigerspool-<model>-photo-<view>.jpg
```

`-map_metadata -1` drops the metadata; ffmpeg applies the phone's rotation to
the pixels first, so the picture stays the right way up. Look at the
background too: a photo on a desk shows whatever else is on that desk.
`verify.sh` refuses a picture that still carries EXIF.

### Before a 3MF is committed

A slicer project records more than geometry. It keeps the **full path** of the
file each object was imported from - a user name and a folder layout, on a
public repository - and every object's name as the designer typed it.

```bash
python3 scripts/clean-3mf.py Model3D/<Brand>/<Model>/<Slicer>/*.3mf
```

cuts every source path down to its file name and prints every object name, so
you read them before anyone else does. `verify.sh` refuses a 3MF that still
carries a path.

## Contributing a model

1. Read the rule at the top. If your design needs different electronics, it is a
   fork, not a model.
2. **Print it and build one.** Fit, screen angle and read distance are not
   things a render tells you.
3. **Measure the read distance through the shell.** A case that pushes the
   antenna past ~4 cm produces a device that looks fine and reads nothing.
4. Copy [TEMPLATE.md](TEMPLATE.md) to your directory as `README.md` and fill
   it in: print settings, a photo, which printers it fits.
5. Include the editable source (`.step`, and the native file if you have one)
   so the next person can adapt it.
6. Run `scripts/clean-3mf.py` on your projects, then `bash scripts/verify.sh --quick`.
7. Add a row to the brand's README, and open a PR. See [../CONTRIBUTING.md](../CONTRIBUTING.md).

A model that has been printed and used beats a model that has been designed.

---

## Licensing

Model files contributed here are MIT-licensed like the rest of the repository
([../LICENSE](../LICENSE)). Do not contribute geometry derived from a
manufacturer's proprietary CAD, or from a model whose own license does not permit
redistribution.

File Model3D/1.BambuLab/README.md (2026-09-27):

# Bambu Lab

Cases that mount a TigerSpool on a Bambu Lab printer, one directory per printer
model. The rules every model follows, and the layout inside a model directory,
are in [../README.md](../README.md); a new model starts from
[../TEMPLATE.md](../TEMPLATE.md).

Until one fits your printer, the [desktop stand](../0.Desktop/) works beside any
of them.

| Model | Fits | Directory |
|---|---|---|
| [A1 and A2L](A1-A2/) | Bambu Lab A1, A2L - clips onto the screen | `A1-A2/` |

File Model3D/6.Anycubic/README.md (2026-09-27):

# Anycubic

Cases that mount a TigerSpool on a Anycubic printer, one directory per printer
model. The rules every model follows, and the layout inside a model directory,
are in [../README.md](../README.md); a new model starts from
[../TEMPLATE.md](../TEMPLATE.md).

Until one fits your printer, the [desktop stand](../0.Desktop/) works beside any
of them.

| Model | Fits | Directory |
|---|---|---|
| [Kobra 3 series](Kobra3-Series/) | Anycubic Kobra 3, Kobra 3 V2, Kobra 3 Max, Kobra 3 Max V2 - clips onto the screen | `Kobra3-Series/` |

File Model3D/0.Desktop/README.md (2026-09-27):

# Desktop stand

| Spool on the left | Spool on the right |
|---|---|
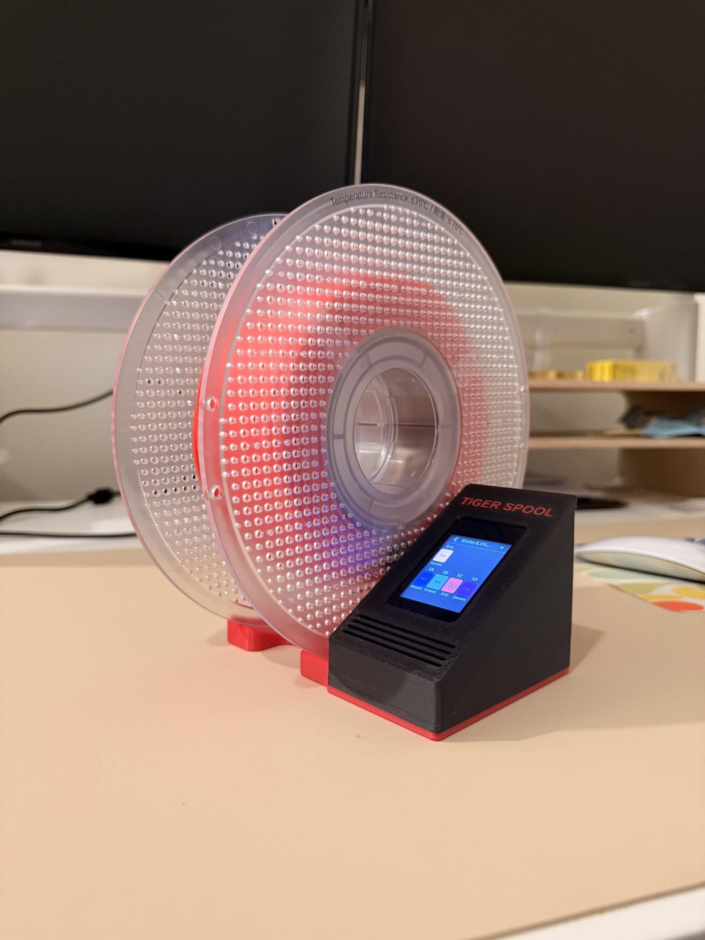
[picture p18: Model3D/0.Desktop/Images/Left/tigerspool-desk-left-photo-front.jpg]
The desktop stand, spool on the left
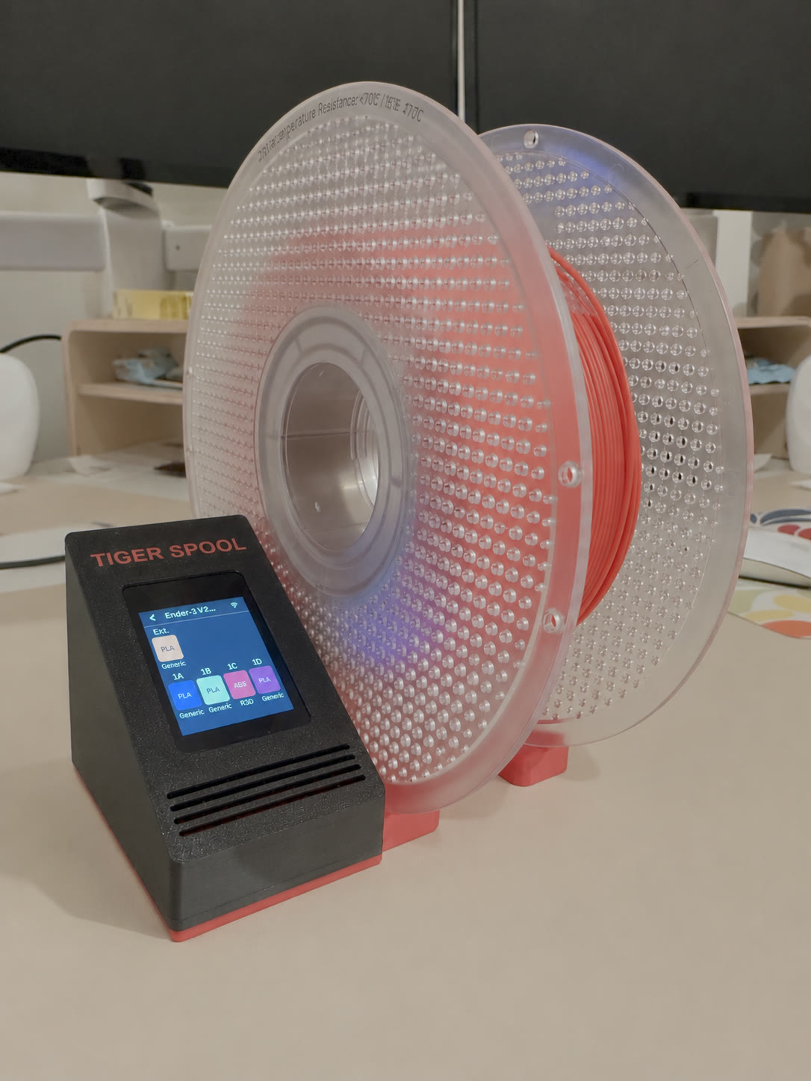
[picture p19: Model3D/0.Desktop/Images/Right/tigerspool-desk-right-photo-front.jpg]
The desktop stand, spool on the right
|  |  |
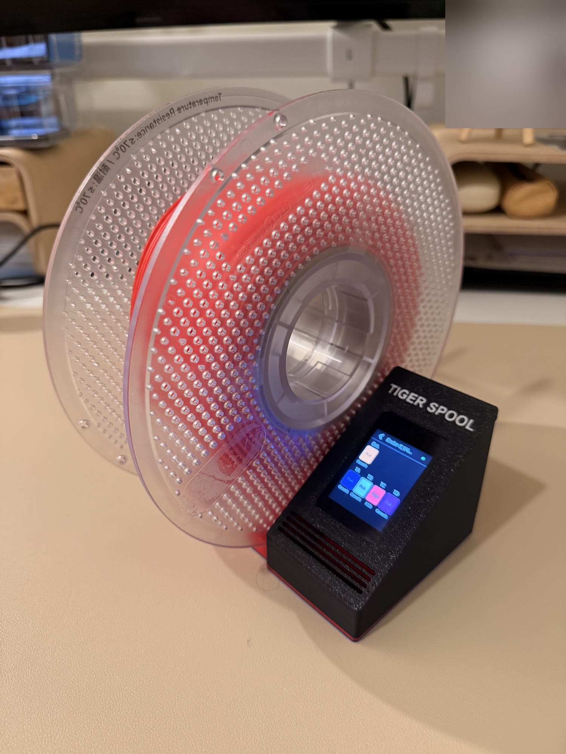
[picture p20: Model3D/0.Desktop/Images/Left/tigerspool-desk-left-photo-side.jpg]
Spool on the left, from the side
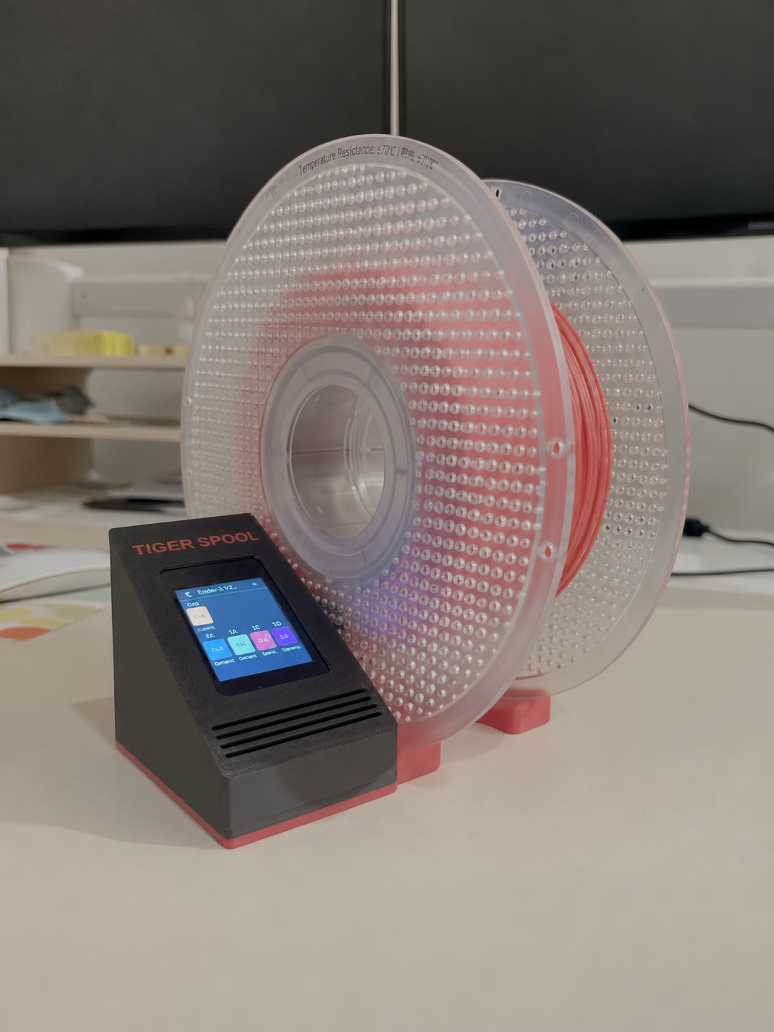
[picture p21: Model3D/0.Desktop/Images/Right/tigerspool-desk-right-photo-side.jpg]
Spool on the right, from the side
|  |  |

**Print it from MakerWorld:**
[spool on the left](https://makerworld.com/models/3360492-tigerspool-desktop-stand-spool-on-the-left) ·
[spool on the right](https://makerworld.com/models/3360619-tigerspool-desktop-stand-spool-on-the-right)

A free-standing stand for the bench or the desk. It is not attached to any
printer, so it fits every one of them - the base TigerSpool, which the
[printer integrations](../README.md) build on.

The stand with a spool resting against the reader

It comes in two mirrored versions: the spool rests **on the left** of the
screen, or **on the right**. Pick the one that suits where it sits.

## Files

Each version is three parts - the base, the display and the display cover.

| | Spool on the left | Spool on the right |
|---|---|---|
| Bambu Studio, every part on one plate | [`tigerspool-desk-left-full.3mf`](BambuStudio/tigerspool-desk-left-full.3mf) | [`tigerspool-desk-right-full.3mf`](BambuStudio/tigerspool-desk-right-full.3mf) |
| Creality Print, every part on one plate | [`tigerspool-desk-left-full.3mf`](CrealityPrint/tigerspool-desk-left-full.3mf) | [`tigerspool-desk-right-full.3mf`](CrealityPrint/tigerspool-desk-right-full.3mf) |
| Base, bare part | [`tigerspool-desk-left-base.3mf`](OriginalFiles/Left/tigerspool-desk-left-base.3mf) | [`tigerspool-desk-right-base.3mf`](OriginalFiles/Right/tigerspool-desk-right-base.3mf) |
| Display, bare part | [`tigerspool-desk-left-display.3mf`](OriginalFiles/Left/tigerspool-desk-left-display.3mf) | [`tigerspool-desk-right-display.3mf`](OriginalFiles/Right/tigerspool-desk-right-display.3mf) |
| Display cover, bare part | [`tigerspool-desk-left-display-cover.3mf`](OriginalFiles/Left/tigerspool-desk-left-display-cover.3mf) | [`tigerspool-desk-right-display-cover.3mf`](OriginalFiles/Right/tigerspool-desk-right-display-cover.3mf) |

The slicer projects carry the orientation, the supports and the settings below.
The bare parts carry geometry only, for any other slicer.

## Assembly

No screws, no inserts, no hardware to buy for the case: it is 100 % 3D
printed. The board and the reader go into the printed parts, and the parts
assemble on their own. Every part is designed to print without supports.

## Print settings

PLA, 0.4 mm nozzle and 15 % infill everywhere. The rest is what each project
was saved with:

| Project | Printer | Layer | Walls | Supports |
|---|---|---|---|---|
| Bambu Studio, left | A1 mini | 0.20 mm | 2 | none |
| Bambu Studio, right | A1 mini | 0.20 mm | 3 | none |
| Creality Print, left | Hi | 0.24 mm | 2 | none |
| Creality Print, right | K2 Pro | 0.20 mm | 3 | tree, painted on where needed |

The display part uses a second PLA colour for its details; the projects assign
it already. Print it in one colour and it still works.

## The parts

| Spool on the left | Spool on the right |
|---|---|
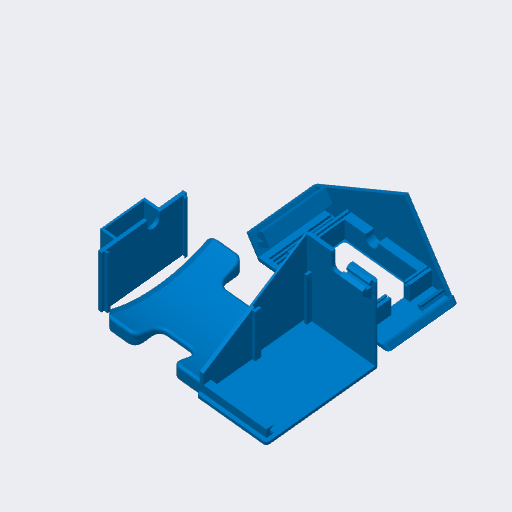
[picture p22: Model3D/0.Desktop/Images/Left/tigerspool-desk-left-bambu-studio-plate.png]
Plate, spool on the left
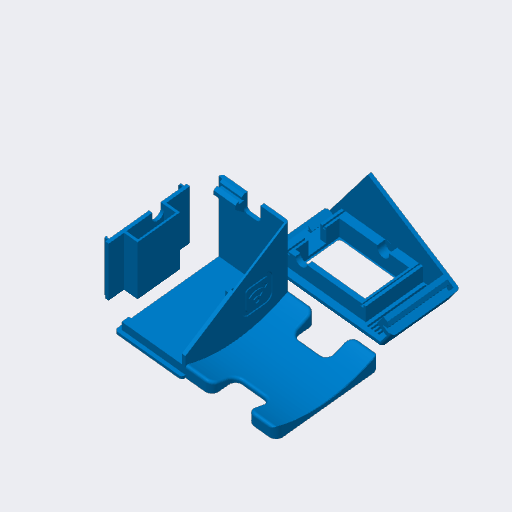
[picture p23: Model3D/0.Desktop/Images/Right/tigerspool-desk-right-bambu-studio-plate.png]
Plate, spool on the right
|  |  |

### From above

| Spool on the left | Spool on the right |
|---|---|
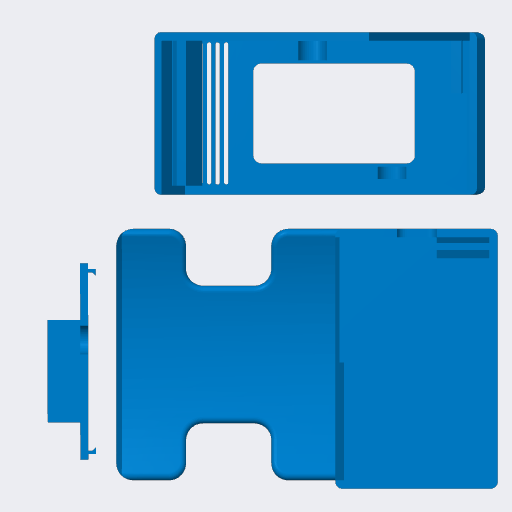
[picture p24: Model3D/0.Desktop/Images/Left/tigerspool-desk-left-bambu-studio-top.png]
Plate from above, spool on the left
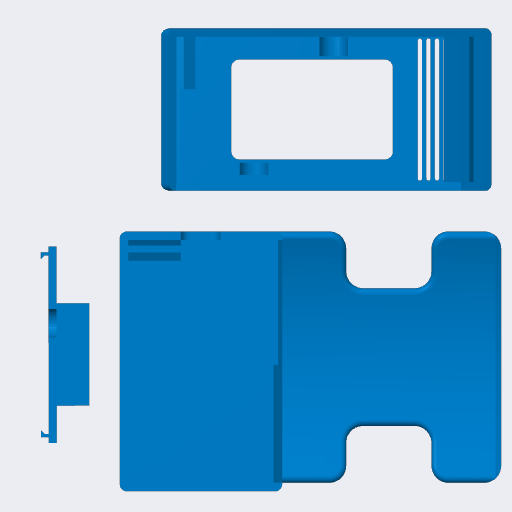
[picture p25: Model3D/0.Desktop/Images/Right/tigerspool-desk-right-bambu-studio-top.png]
Plate from above, spool on the right
|  |  |

The plate pictures are the slicers' own previews, taken out of the projects;
the Creality Print ones and a render of each version are in [`Images/Left/`](Images/Left/) and [`Images/Right/`](Images/Right/) too.

## Source

[`Source/tigerspool-desk.f3d`](Source/tigerspool-desk.f3d) - the Fusion design
both versions come from.

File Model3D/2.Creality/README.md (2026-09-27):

# Creality

Cases that mount a TigerSpool on a Creality printer, one directory per printer
model. The rules every model follows, and the layout inside a model directory,
are in [../README.md](../README.md); a new model starts from
[../TEMPLATE.md](../TEMPLATE.md).

Until one fits your printer, the [desktop stand](../0.Desktop/) works beside any
of them.

| Model | Fits | MakerWorld | Directory |
|---|---|---|---|
| [K2 and K2 Pro](K2-K2Pro/) | Creality K2, K2 Pro - clips onto the screen | [print it](https://makerworld.com/models/3361291-tigerspool-for-creality-k2-and-k2-pro) | `K2-K2Pro/` |

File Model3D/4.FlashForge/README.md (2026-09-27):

# FlashForge

Cases that mount a TigerSpool on a FlashForge printer, one directory per printer
model. The rules every model follows, and the layout inside a model directory,
are in [../README.md](../README.md); a new model starts from
[../TEMPLATE.md](../TEMPLATE.md).

Until one fits your printer, the [desktop stand](../0.Desktop/) works beside any
of them.

| Model | Fits | MakerWorld | Directory |
|---|---|---|---|
| [Creator 5 and Creator 5 Pro](Creator5-5Pro/) | FlashForge Creator 5, Creator 5 Pro - clips onto the screen | [print it](https://makerworld.com/models/3361301-tigerspool-rfid-for-flashforge-creator-5-and-5-pro) | `Creator5-5Pro/` |

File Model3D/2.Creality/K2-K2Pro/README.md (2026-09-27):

# Creality K2 and K2 Pro

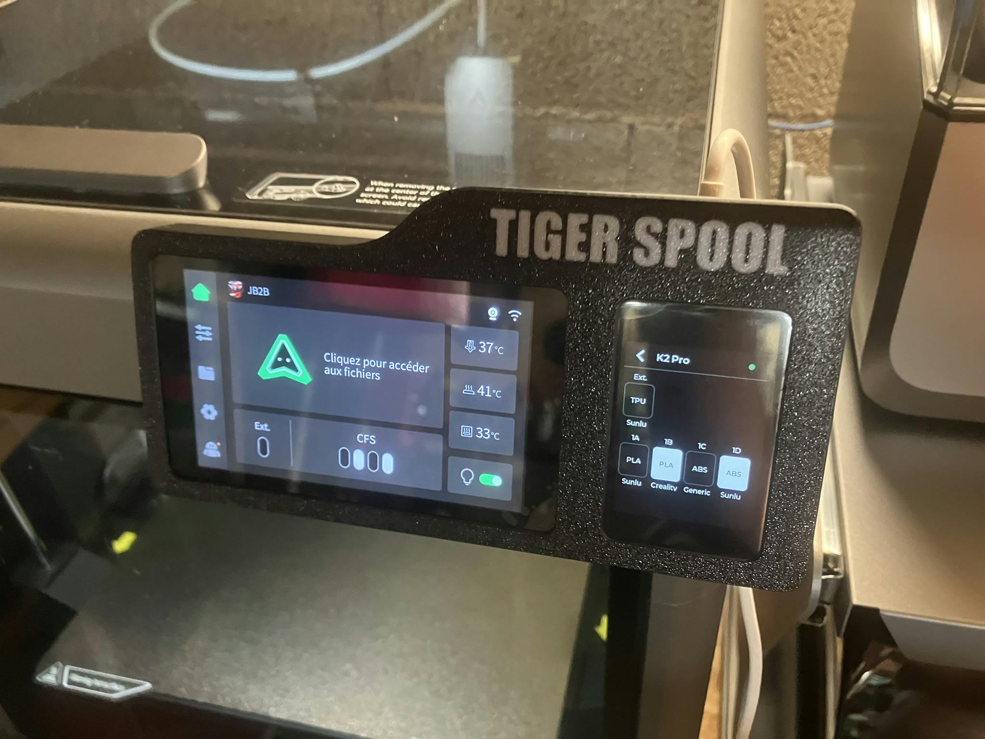
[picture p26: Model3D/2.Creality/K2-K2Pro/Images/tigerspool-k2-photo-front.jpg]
The case on a K2 Pro, clipped onto its touchscreen
 The case from the side, with the reader

**Print it from MakerWorld:
[TigerSpool for Creality K2 and K2 Pro](https://makerworld.com/models/3361291-tigerspool-for-creality-k2-and-k2-pro)**

A printer integration of the [desktop stand](../../0.Desktop/) for the Creality
K2 and K2 Pro: the same TigerSpool, in a case that clips onto the printer's own
touchscreen, with the TigerSpool screen beside it and the reader on the side -
right above the CFS.

Nothing to switch on: the K2 accepts TigerSpool's local requests while it stays
on Creality Cloud.

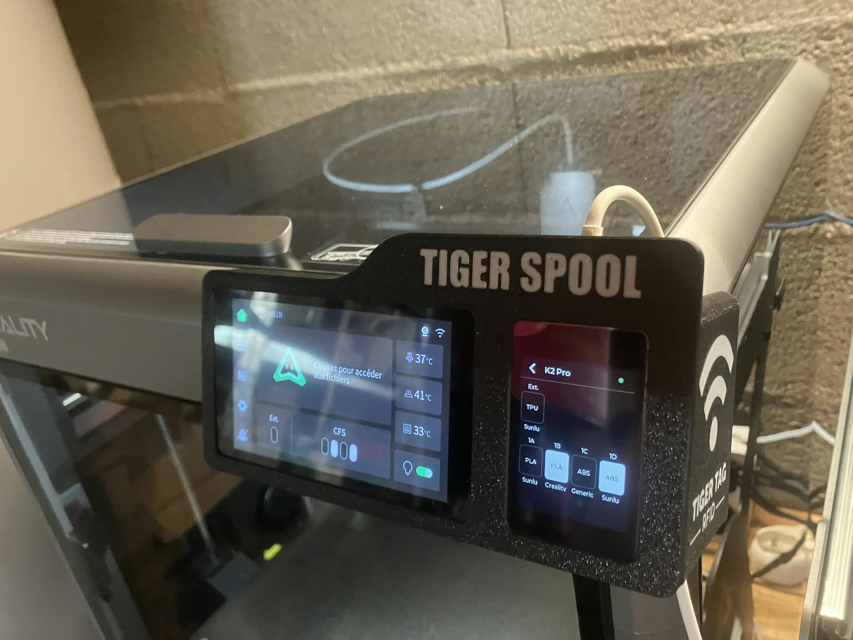
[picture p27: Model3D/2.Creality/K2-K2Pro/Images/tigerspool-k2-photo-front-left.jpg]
The case on the printer, from the front left


## Parts

| Part | File |
|---|---|
| Frame | [`tigerspool-k2-frame.3mf`](OriginalFiles/tigerspool-k2-frame.3mf) |
| Cover | [`tigerspool-k2-cover.3mf`](OriginalFiles/tigerspool-k2-cover.3mf) |
| RFID reader holder | [`tigerspool-k2-rfid.3mf`](OriginalFiles/tigerspool-k2-rfid.3mf) |
| Everything, one plate - Creality Print, K2 | [`tigerspool-k2-full.3mf`](CrealityPrint/tigerspool-k2-full.3mf) |
| Everything, one plate - Creality Print, K2 Pro | [`tigerspool-k2pro-full.3mf`](CrealityPrint/tigerspool-k2pro-full.3mf) |
| Everything, one plate - Bambu Studio | [`tigerspool-k2-full.3mf`](BambuStudio/tigerspool-k2-full.3mf) |

The bare parts carry geometry only, for any slicer; each project carries the
orientation, the supports and the settings below.

## Print settings

PLA, 0.4 mm nozzle, 0.20 mm layers and 15 % infill in every project.

| Project | Printer | Walls | Supports |
|---|---|---|---|
| Creality Print | K2 | 2 | none |
| Creality Print | K2 Pro | 3 | none |
| Bambu Studio | A1 mini | 3 | normal, placed by hand |

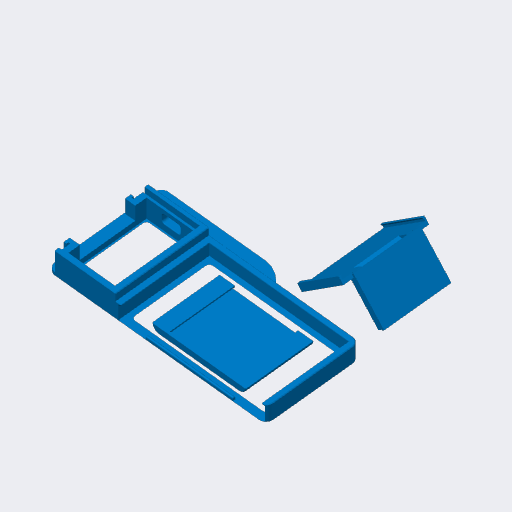
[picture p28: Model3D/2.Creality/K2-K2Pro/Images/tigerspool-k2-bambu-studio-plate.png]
The parts on the Bambu Studio plate


## Source

[`Source/tigerspool-k2.f3d`](Source/tigerspool-k2.f3d) - the Fusion design.

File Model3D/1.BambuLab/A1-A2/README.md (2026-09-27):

# Bambu Lab A1 and A2L

The parts on the Bambu Studio plate

A TigerSpool case made for the Bambu Lab A1 and A2L. It clips onto the
printer's screen.

## Parts

| Part | File |
|---|---|
| Frame | [`tigerspool-a1-a2-frame.3mf`](OriginalFiles/tigerspool-a1-a2-frame.3mf) |
| Cover, with the logo | [`tigerspool-a1-a2-cover.3mf`](OriginalFiles/tigerspool-a1-a2-cover.3mf) |
| RFID reader holder | [`tigerspool-a1-a2-rfid.3mf`](OriginalFiles/tigerspool-a1-a2-rfid.3mf) |
| Everything, one plate (Bambu Studio) | [`tigerspool-a1-a2-full.3mf`](BambuStudio/tigerspool-a1-a2-full.3mf) |

The bare parts carry geometry only, for any slicer; the Bambu Studio project
carries the orientation, the supports and the settings below.

## Print settings

Saved from Bambu Studio for an A1 mini, 0.4 mm nozzle.

| Setting | Value |
|---|---|
| Layer height | 0.20 mm |
| Walls | 3 |
| Infill | 15 % |
| Supports | normal, placed by hand - they are in the project |
| Material | PLA (Bambu PLA Basic in the project), two colours for the cover logo |

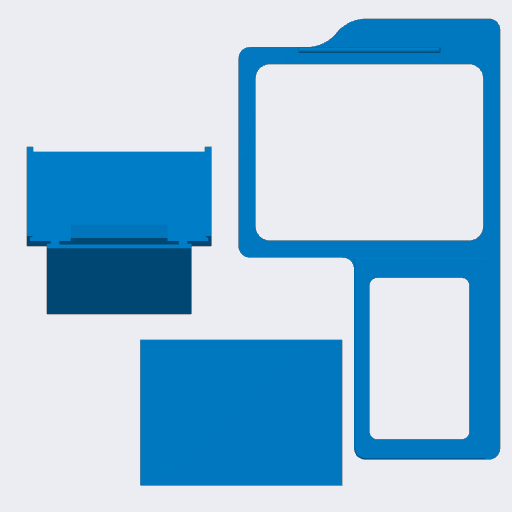
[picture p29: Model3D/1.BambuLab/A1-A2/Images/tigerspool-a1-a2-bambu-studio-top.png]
The plate from above


## Source

[`Source/tigerspool-a1-a2.f3d`](Source/tigerspool-a1-a2.f3d) - the Fusion design.

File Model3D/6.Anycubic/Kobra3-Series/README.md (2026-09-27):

# Anycubic Kobra 3 series

The parts on the Bambu Studio plate

A printer integration of the [desktop stand](../../0.Desktop/) for every
Anycubic Kobra 3 model: the same TigerSpool, in a case that clips onto the
printer's screen. It fits:

- Anycubic Kobra 3
- Anycubic Kobra 3 V2
- Anycubic Kobra 3 Max
- Anycubic Kobra 3 Max V2

## Parts

| Part | File |
|---|---|
| Frame | [`tigerspool-kobra3-frame.3mf`](OriginalFiles/tigerspool-kobra3-frame.3mf) |
| Cover | [`tigerspool-kobra3-cover.3mf`](OriginalFiles/tigerspool-kobra3-cover.3mf) |
| RFID reader holder | [`tigerspool-kobra3-rfid.3mf`](OriginalFiles/tigerspool-kobra3-rfid.3mf) |
| Everything, one plate (Bambu Studio, ready to print) | [`tigerspool-kobra3-full.3mf`](BambuStudio/tigerspool-kobra3-full.3mf) |

The bare parts carry geometry only, for any slicer; the Bambu Studio project
carries the orientation, the supports and the settings below.

## Print settings

Saved from Bambu Studio for an A1, 0.4 mm nozzle.

| Setting | Value |
|---|---|
| Layer height | 0.20 mm |
| Walls | 2 |
| Infill | 15 % |
| Supports | normal, placed by hand - they are in the project |
| Material | PLA (Bambu PLA Basic in the project), two colours |

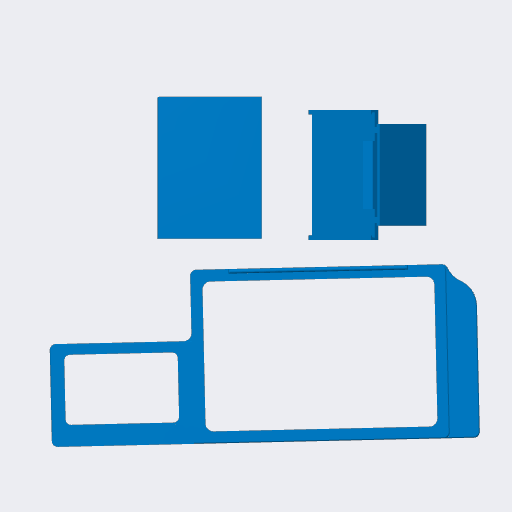
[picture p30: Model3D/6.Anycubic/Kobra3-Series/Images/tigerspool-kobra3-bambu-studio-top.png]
The plate from above


## Source

[`Source/tigerspool-kobra3.f3d`](Source/tigerspool-kobra3.f3d) - the Fusion design.

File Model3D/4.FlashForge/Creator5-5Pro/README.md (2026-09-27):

# FlashForge Creator 5 and Creator 5 Pro

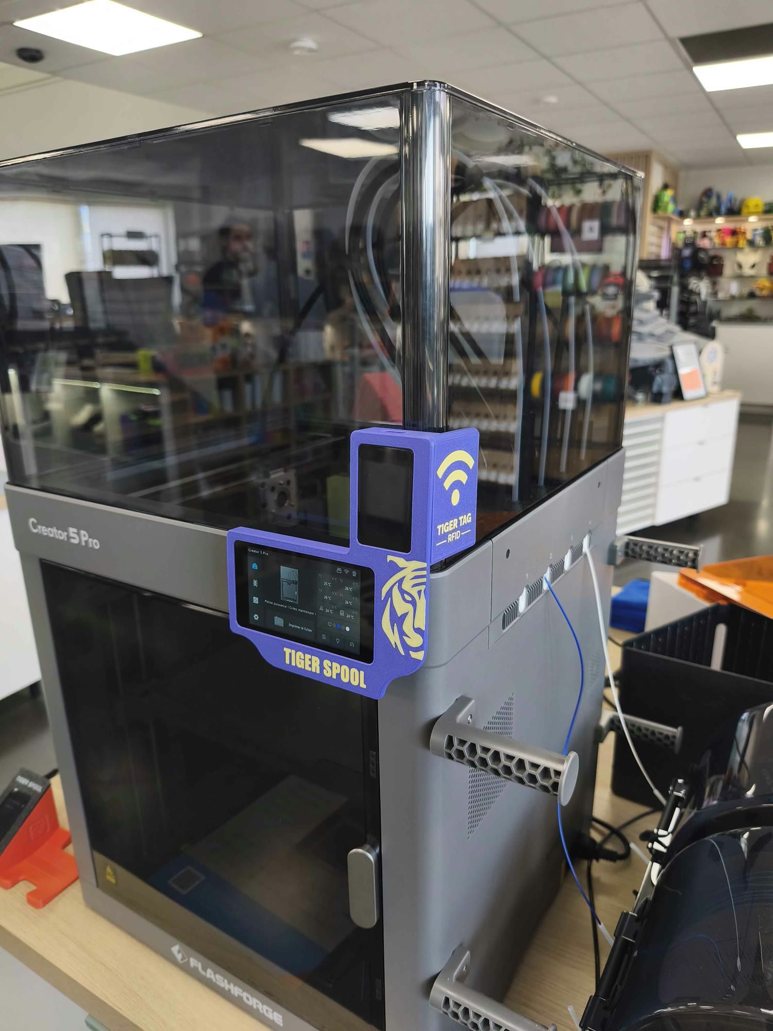
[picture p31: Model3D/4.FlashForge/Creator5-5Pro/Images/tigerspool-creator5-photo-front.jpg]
The case on a Creator 5 Pro, clipped onto its screen
 Close-up of the case on the printer

**Print it from MakerWorld:
[TigerSpool for FlashForge Creator 5 and 5 Pro](https://makerworld.com/models/3361301-tigerspool-rfid-for-flashforge-creator-5-and-5-pro)**

A printer integration of the [desktop stand](../../0.Desktop/) for the
FlashForge Creator 5 and Creator 5 Pro: the same TigerSpool, in a case that
clips onto the printer's screen, with the TigerSpool screen and the reader
beside it - where the spools go into slots 1A to 1D.

## Recommended: the FlashForge × TigerSystem firmware

TigerSpool talks to the printer over your local network. With FlashForge's
standard firmware, **turning LAN mode on turns FlashForge Cloud off**. The
FlashForge × TigerSystem firmware - an official FlashForge build, developed by
their engineering team at TigerTag's request - keeps both on at once. It is
free.

| | Standard firmware | FlashForge × TigerSystem |
|---|---|---|
| FlashForge Cloud - app, remote access | ✓ | ✓ |
| LAN - local tools on your network | ✓ | ✓ |
| Both at the same time | ✕ | ✓ |
| Tiger Studio, Tiger NFC Connect and TigerSpool with Cloud on | ✕ | ✓ |

Download: [Creator 5](https://tigertag-project.github.io/FlashForge-TigerTag-Creator5-Firmware-Lan-and-Cloud/download/creator5/) ·
[Creator 5 Pro](https://tigertag-project.github.io/FlashForge-TigerTag-Creator5-Firmware-Lan-and-Cloud/download/creator5pro/).
It installs from a FAT32 USB drive, the file at its root, printer off; switch
on and it installs itself. Then turn LAN mode on. **Do not accept the printer's
own online update afterwards** - it puts the standard firmware back, and Cloud
+ LAN with it; reinstall from USB if it happened.

Thank you, FlashForge: opening a printer to an ecosystem that is not your own
is a rare decision.

## Parts

| Part | File |
|---|---|
| Frame | [`tigerspool-creator5-frame.3mf`](OriginalFiles/tigerspool-creator5-frame.3mf) |
| Cover | [`tigerspool-creator5-cover.3mf`](OriginalFiles/tigerspool-creator5-cover.3mf) |
| RFID reader holder | [`tigerspool-creator5-rfid.3mf`](OriginalFiles/tigerspool-creator5-rfid.3mf) |
| Everything, one plate (Bambu Studio) | [`tigerspool-creator5-full.3mf`](BambuStudio/tigerspool-creator5-full.3mf) |

The bare parts carry geometry only, for any slicer - FlashForge Orca included;
the Bambu Studio project carries the orientation, the supports and the
settings below.

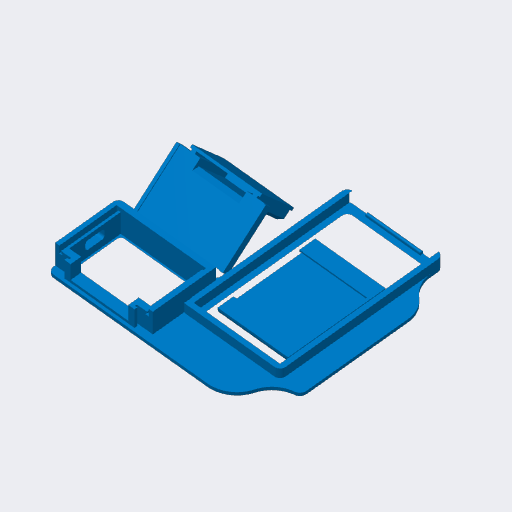
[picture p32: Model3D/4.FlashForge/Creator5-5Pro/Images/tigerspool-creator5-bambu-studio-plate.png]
The parts on the Bambu Studio plate


## Print settings

Saved from Bambu Studio for an A1 mini, 0.4 mm nozzle.

| Setting | Value |
|---|---|
| Layer height | 0.20 mm |
| Walls | 3 |
| Infill | 15 % |
| Supports | normal, placed by hand - they are in the project |
| Material | PLA (Bambu PLA Basic in the project), two colours |

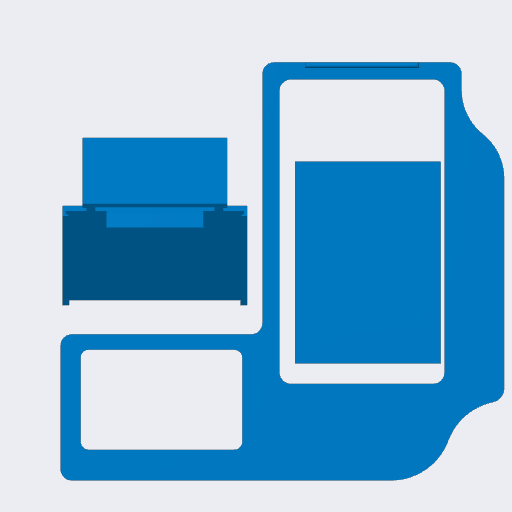
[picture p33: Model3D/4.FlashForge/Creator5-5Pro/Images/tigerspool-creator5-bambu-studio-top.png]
The plate from above


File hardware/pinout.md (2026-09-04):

# Pinout

Quick reference. The reasoning, the failure modes and the bring-up checklist are
in **[../docs/WIRING.md](../docs/WIRING.md)** — read that before wiring a board
for the first time.

**Board:** Waveshare ESP32-S3-Touch-LCD-2 (ESP32-S3R8, 16 MB flash, 8 MB octal PSRAM)

## What you wire

| Function | ESP32-S3 GPIO | Connects to | Direction |
|---|---|---|---|
| PN532 power | `3V3` | PN532 `VCC` | — |
| Ground | `GND` | PN532 `GND` | — |
| UART1 RX | **44** | PN532 `TXD` | in |
| UART1 TX | **43** | PN532 `RXD` | out |
| ~~Reader reset~~ | — | PN532 `RSTO` | **not connected** — the firmware drives no reset line |

UART1, 115200 baud, 8N1. PN532 DIP switches both `0` / OFF.

> ⚠️ **Not GPIO6/7.** They carry an I²C bus with pull-ups on this board and
> corrupt every read while appearing to work.

## Already on the board

Listed so you know which pins are taken. Nothing to wire here.

| Function | GPIO |
|---|---|
| LCD `SCLK` (SPI3) | 39 |
| LCD `MOSI` | 38 |
| LCD `MISO` | 40 |
| LCD `DC` | 42 |
| LCD `CS` | 45 |
| LCD backlight | 1 |
| Touch `SDA` (I²C0) | 48 |
| Touch `SCL` | 47 |

Touch controller: CST816S at address `0x15`. Display rotation: `2` (portrait,
180°).

## Unavailable pins

| GPIO | Reason |
|---|---|
| 0 | Strapping / BOOT |
| 6, 7 | On-board I²C with pull-ups |
| 19, 20 | Native USB |
| 26–32 | SPI flash |
| 33–37 | Octal PSRAM |
| 45, 46 | Strapping |
| 47, 48 | Touch I²C |

GPIO43/44 are free only because the console runs over USB-CDC. The build must
keep `-DARDUINO_USB_MODE=1` and `-DARDUINO_USB_CDC_ON_BOOT=1`.

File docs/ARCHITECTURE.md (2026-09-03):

# Architecture

What the firmware is made of, and why it is divided the way it is.

This describes the **target** architecture. The prototype it derives from is
close but not identical; [MIGRATION.md](MIGRATION.md) is the diff.

---

## The one idea

A printer backend knows one thing: **how to put a material, a colour and two
temperatures into slot _n_ of one specific printer.** It knows nothing about NFC,
nothing about the screen, and nothing about Wi-Fi.

Everything above it — the UI, the reader, the account — is written once and works
for every printer. Everything below it is per-brand and stays contained. Adding
Elegoo means writing one class, not touching the application.

---

## Layers

```
┌───────────────────────────────────────────────────────────────┐
│  ui/            screens, touch handling, rendering            │
│                 knows: state machine, layout                  │
│                 knows nothing about: NFC, MQTT, HTTP, Firebase│
├───────────────────────────────────────────────────────────────┤
│  app/           state machine, device orchestration           │
│                 owns the transitions and the selected printer │
├───────────────┬──────────────┬────────────────┬───────────────┤
│  reader/      │  printers/   │  account/      │  net/         │
│  PN532 HSU    │  backends    │  TigerTag      │  Wi-Fi, portal│
│  TigerTag     │  + registry  │  session,      │  mDNS, OTA,   │
│  decode       │              │  printers in,  │  web config   │
│               │              │  slots out     │               │
├───────────────┴──────────────┴────────────────┴───────────────┤
│  platform/      NVS, display driver, touch, time, logging     │
└───────────────────────────────────────────────────────────────┘
```

Each layer may call downwards. Nothing calls upwards; a backend that wants to
tell the user something returns a status, it does not draw.

### Why `net/` is one layer and not per-feature

Wi-Fi provisioning, the configuration web server, mDNS and OTA all share the same
scarce resource — the radio and one TCP stack — and all of them have to behave
when the network goes away mid-operation. Keeping them adjacent is what stops
four independent reconnection policies from fighting each other.

---

## Printer abstraction

### The interface

Every printer implements the same small surface. The prototype's version, which
has survived four protocols unchanged, is the starting point:

```cpp
class PrinterBackend {
public:
    virtual void begin(const PrinterCfg& cfg) = 0;  // open the connection
    virtual void loop()                       = 0;  // pump the transport
    virtual void stop()                       = 0;  // close, free the heap
    virtual bool connected()                  = 0;

    virtual int         slotCount()           = 0;  // how many slots exist
    virtual const char* slotLabel(int i)      = 0;  // "Ext", "1A", "T3"…
    virtual const SlotState& slot(int i)      = 0;  // what's in slot i now
    virtual bool assign(int i, const TagInfo& t) = 0;  // put this filament there

    virtual String status()                   = 0;
    virtual void   refresh()                  = 0;  // re-read slot state
};
```

Three things make this work across protocols as different as MQTT and HTTP
polling:

**Slots are a flat 0-based list to the UI.** Real printers do not agree on
addressing — Creality has box+slot pairs, Bambu has AMS unit + tray with special
values for the external spool, FlashForge has 1-based slot ids, Snapmaker has
extruder indices, Anycubic has box+slot with a four-slot box numbered `-1`.
Every one of those mappings lives *inside* its backend. The grid on screen
iterates `0 … slotCount()-1` and never learns the difference.

> The TigerTag account already models slots this way, normalised across brands,
> each entry carrying a `hw` object holding the printer's own address. The
> firmware and Tiger Studio arrived at the same split independently, which is
> decent evidence it is the right one — and it means the two can be aligned
> rather than merely compatible.
> [ACCOUNT-DATA.md](ACCOUNT-DATA.md#units--the-slot-model-the-ecosystem-already-agreed-on)

**`slotCount()` is dynamic.** A Bambu Lab printer's slot count is not known until
its first status report arrives — one AMS unit or four, plus the external spool.
The UI paginates whatever number it is told.

**`assign()` takes a decoded tag, not a protocol payload.** Translating "PETG,
Polymaker, #1A5C0C, 230/240 °C" into whatever the printer will accept is the
backend's entire job, and it is where the per-brand ugliness lives — see below.

### Transport vs. protocol

These are separated because they vary independently. Two printers can share a
transport and share nothing else — Bambu Lab, Elegoo and Anycubic all speak MQTT
and agree on nothing above it, including whether there is any TLS.

| Backend | Transport | Protocol |
|---|---|---|
| Creality | WebSocket, port 9999 | proprietary JSON, `get`/`set` envelopes |
| FlashForge | HTTP POST, port 8898 | JSON with credentials in every request body |
| Bambu Lab | MQTT over TLS, port 8883 | JSON commands on `device/{SN}/request` |
| Snapmaker | WebSocket, port 7125 | Moonraker JSON-RPC 2.0, no auth |
| Elegoo | MQTT, port 1883, **plain TCP** | numbered JSON methods on `elegoo/{sn}/…` topics |
| Anycubic | MQTT over TLS, port 9883 | JSON actions on an `anycubic/…/multiColorBox` topic |

The transport layer answers: how do bytes get there, how does the connection
recover, what does authentication look like. The protocol layer answers: what
does "set the filament in slot 2" spell out to.

### The part nobody expects: material and colour translation

Backends are not thin. The tag says exactly what the filament is; printers accept
only what they already know about, and each is differently stubborn:

- **Bambu Lab** wants a `tray_info_idx` code (`GFL99` for generic PLA, `GFG99`
  for PETG…) and accepts **any** RGB colour.
- **FlashForge Creator 5** accepts only the **24 colours in its own palette** and
  a material name from **its own list of 21**. Send anything else and it answers
  "success" while silently resetting the slot to white. Colour has to be snapped
  to the nearest palette entry, material to the nearest known name.
- **Creality** wants a 7-digit `#0RRGGBB` colour — a `0` after the `#`, not a
  6-digit hex.
- **Snapmaker** takes G-code arguments, so any space in a vendor or material name
  has to become an underscore or the command is silently mis-parsed.
- **Elegoo** wants a `filament_code` looked up from a 50-entry table keyed by
  material type *and* variant name, and a `filament_type` stripped back to its
  base token — `"PLA+ Silk"` has to become `"PLA"`.
- **Anycubic** takes a `[r, g, b]` array and accepts only `{index, type, color}`;
  richer fields are acknowledged and silently dropped. Pure black `[0,0,0]`
  renders as *empty* on the ACE display and has to be nudged to `[1,1,1]`.

This translation is a first-class part of every backend, not an afterthought.
Each one needs its own tests, and each is a place where a printer firmware update
can break us.

> **A lesson worth writing down:** on FlashForge, an unknown command is
> acknowledged with `{code:0}` anyway. **Success is not evidence of effect.** Any
> backend whose protocol can lie must confirm by re-reading state after a write.

### The registry

Backends register themselves; the application never contains a `switch` over
brands. Adding one means adding a file and a registration line, and that is what
keeps a new brand from touching the UI.

---

## State machine

```
                    ┌──────────┐
     first boot ───▶│   LANG   │  pick a language, once
                    └────┬─────┘
                         ▼
                    ┌──────────┐  credentials in NVS?
              ┌────▶│   WIFI   │──── no / fails ──┐
              │     └────┬─────┘                  ▼
              │          │ connected      ┌──────────────┐
              │          │                │  PROVISION   │  built-in captive
              │          │                │              │  portal + Wi-Fi QR
              │          │                └──────┬───────┘
              │          │                       │ saved
              │          │◀──────────────────────┘  (reboot)
              │          ▼
              │     ┌──────────┐  no account linked?
              │     │  ACCOUNT │──────────────────┐
              │     └────┬─────┘                  ▼
              │          │ linked          ┌──────────────┐
              │          │                 │   PAIRING    │  QR + short code,
              │          │                 │              │  poll until approved
              │          │                 └──────┬───────┘
              │          │◀───────────────────────┘
              │          ▼
              │     ┌──────────┐  the printers imported from the account
              │     │ PRINTERS │  paginated list, online/offline dots
              │     └────┬─────┘
              │          │ tap a printer  ──▶ backend->begin()
              │          ▼
              │     ┌──────────┐  slot grid, colours and materials read live
              └─────│   GRID   │◀────────────────────────────┐
             back   └────┬─────┘                             │
                         │ tap a slot                        │
                         ▼                                   │
                    ┌──────────┐  "hold the spool to the box" │
                    │   SCAN   │──── cancel ─────────────────▶│
                    └────┬─────┘                              │
                         │ tag decoded                        │
                         ▼                                    │
                    ┌──────────┐  colour swatch, material,    │
                    │  REVIEW  │  brand, temperatures         │
                    └────┬─────┘  [ No ]        [ Send ] ─────┤
                         │ Send → backend->assign(slot, tag)  │
                         ▼                                    │
                    ┌──────────┐  OK / error + reason         │
                    │  RESULT  │──── tap, or 2.5 s ──────────▶┘
                    └──────────┘
```

**Design rules for the state machine:**

- **The screen never blocks.** Anything that can take seconds — a network scan, an
  account sync, an OTA download — either runs incrementally across `loop()` calls
  or gets its own screen with progress. A frozen 2.0" screen is indistinguishable
  from a crashed device.
- **Every failure state names a way out.** "Printer offline" is not an error
  message; "Printer offline — check it is on the same network" is.
- **`PROVISION` and `PAIRING` are states, not separate firmwares.** See
  [WIFI-PROVISIONING.md](WIFI-PROVISIONING.md) and
  [ACCOUNT-PAIRING.md](ACCOUNT-PAIRING.md).
- **`RESULT` writes back to the account, in the background.** A confirmed
  assignment updates the slot in the user's account — material, colour, vendor,
  and the scanned tag's UID — so a spool scanned in the workshop is visible in
  Tiger Studio and on a phone. It happens after the result screen, never blocks
  it, and never runs for a cloud-mode printer whose state the vendor's cloud
  already owns. [ACCOUNT-DATA.md](ACCOUNT-DATA.md#writing-back)

---

## Configuration and storage

Everything persistent lives in NVS under the namespace **`tigerspool`**.

| Key group | Holds |
|---|---|
| `ssid`, `pass` | Wi-Fi credentials |
| `lang` | selected language |
| `p0…p7` | up to eight printers: type, name, host, serial, access code |
| `psel` | which printer is selected |
| account | refresh token, uid, email — encrypted, see below |

**Printers are imported, not typed.** The account sync writes `p0…p7`; the web
form exists to correct an import or to add a printer the account does not know
about, and it merges rather than overwrites, so a value a user corrected by hand
is not clobbered by the next sync.

**A printer's credentials are not a fixed shape, and the config must stop
pretending they are.** The prototype models every printer as
`{type, name, host, sn, cc}` — enough for a serial and one access code, which
covers Creality, FlashForge, Bambu Lab, Snapmaker and Elegoo. **Anycubic does
not fit**: it needs a broker `deviceId`, a `username`, a `password` and a numeric
`acuModelId` that forms part of the MQTT topic. Cloud-mode printers carry
different fields again.

Bolting `sn2`/`cc2` onto the struct is how this ends up unreadable by the third
brand. The credential set belongs to the backend that consumes it — a small
key/value bag the account layer fills and the backend reads by name — so adding a
brand with unusual authentication stays a change inside that brand.

The observed field names, per brand, are in
[ACCOUNT-DATA.md](ACCOUNT-DATA.md#credentials-are-not-one-shape). Six brands use
six different vocabularies, and one of them shares no spelling with any other.

**The account token is stored in encrypted NVS.** A refresh token is a
long-lived credential to someone's account. It does not sit in plaintext flash
where a `esptool read_flash` recovers it. See [SECURITY.md](../SECURITY.md).

**No credentials are ever compiled in.** Not Wi-Fi, not printer access codes, not
API keys with any authority. The published firmware binary is identical for every
user.

---

## Identifiers

Fixed now so that nothing has to be renamed later. The prototype's `k2`/`tigertag`
names belong to a Creality-only ancestor and do not survive.

| | Value |
|---|---|
| mDNS hostname | `tigerspool-xxxx.local` |
| Setup AP SSID | `TigerSpool-Setup-XXXX` |
| Firmware binary | `tigerspool-v1.0.0.bin` |
| PlatformIO env | `tigerspool` |
| MQTT client id | `tigerspool-<mac6>` |
| NVS namespace | `tigerspool` |

---

## Directory layout

The source tree is mapped in [CODEMAP.md](../CODEMAP.md): what each file owns,
what it must not be asked to do, and the landmines to read before editing it.
It is kept there rather than here so there is one description of the layout
rather than two that drift.

**One copy of the PN532 library**, vendored under `firmware/lib/PN532/`. The
prototype carried three, which had already drifted apart from each other. See
[MIGRATION.md](MIGRATION.md#the-vendored-pn532-library).

---

## Open questions

Recorded here rather than answered wrongly.

- **Recovering a wedged reader at runtime.** The reset line helps at init. Whether
  it can recover a reader that stops responding after hours, without a power
  cycle, is untested.
- **Backend memory ceiling.** Bambu Lab's full status report can reach ~50 KB and
  needs a large MQTT buffer. Only one backend is active at a time, which is what
  makes this fit; whether that constraint should be enforced by the registry
  rather than by convention is undecided.
- **Behaviour during a print.** Reassigning a slot mid-print is at best ignored
  and at worst harmful on some printers. Whether the firmware should detect and
  refuse it, and how it learns the printer is printing, is not designed yet.

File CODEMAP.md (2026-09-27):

# Code map

**The [Landmines](#landmines) table is this file.** Everything above it is the
short list of module facts that `ls` and `grep` do not give you; everything a
grep would have told you has been deliberately left out.

No line numbers are recorded here: nothing verifies them, and a number nothing
verifies is a number that lies. Grep for the symbol. If a file has outgrown what
this says, say so rather than working around it.

Build-level and hardware-level facts live in [CLAUDE.md](CLAUDE.md) and are not
repeated here.

## Modules worth a note

| File | What is not obvious |
|---|---|
| `main.cpp` | Owns the state machine and the only writable copy of device state — and also owns the display device itself (`lcd`, and the PSRAM `canvas` sprite that exists solely so `/screen.bmp` has something to serialise). It draws no widgets, and must not start: screens render from state passed in. It also carries an inline Creality LAN scanner, which is not where anyone looks for it. |
| `webcfg.cpp`, account page | Signed in, `/login` is the account page, and it **never syncs or switches anything itself**. Its handlers run on the loop task: a sync there nested a TLS handshake in a web handler, overflowed the loop's 8 KB stack on every email sign-in, and held the screen still for the whole sync. So a handler calls `ttcloud::requestSync()` and the loop starts the task; a printer switch is a mask read by `takePrinterSwitch()` and applied by `main.cpp` through `tryToggle()`, the device's own switch and budget check. `/api/account` answers anyone on the LAN, so it carries names, brands and addresses and never a serial or an access code. |
| `webcfg.cpp` | Serves **two** web interfaces — the captive portal for setup, and a separate legacy configuration page over the LAN once provisioned — and has **two** independent Wi-Fi scanners, one async and JSON for the portal, one blocking and HTML for the legacy page. "Change the web page" or "fix the scan" usually means changing the wrong one. |
| `tt_db.cpp` | The TigerTag reference tables exist **twice**, and every lookup goes through here rather than through `tigertag_db.h`. The compiled tables are the floor - what a brand-new box knows offline - and the downloaded ones in LittleFS are preferred when they parse. The fallback is per table, not all-or-nothing, so a corrupt brand file does not throw away a good material file. Calling `tt_material()` directly bypasses the whole mechanism and looks identical until a spool from last month reads as `brand#48804`. The material table keeps more than labels - `crealityID`, `crealityPressureAdvance` and the recommended nozzle window, in the download and in `TT_MATERIAL_INFO` - and `materialInfo()` answers from the same layer as `material()`. |
| `printer_budget.h` | Decides whether a printer may be **switched on**, in *load slots* - one is a kilobyte of internal RAM. It never sees memory: the prices are constants taken from `/api/memtest`, and `docs/CONNECTION-BUDGET.md` holds the measurements they must stay equal to. A new brand with no entry in `loadSlotsFor()` costs 0 and is never refused. "Load slot", never plain "slot" - a slot is a spool tray everywhere else in this code. |
| `backend_bambu.cpp`, external spool | **Read as ams 255 / tray 254, written as ams 255 / tray 0 / slot 0.** A write to tray 254 is accepted and ignored by current firmware (X1C 01.12). The first report after a new MQTT connection carries an empty external tray before the real one. |
| `bambu_cloud.cpp` | One MQTT/TLS session shared by **every** cloud Bambu on the account; `backend_bambu.cpp` attaches and detaches, ref-counted. Reports are routed by the serial in the topic and nothing else - a report is never handed to a printer it did not name. So one cloud printer's "connected" is the session's, and closing one printer does not close the session while another is attached. LAN Bambus do not use it. |
| `anycubic_cloud.cpp` | One MQTT/TLS session to Anycubic's cloud broker, shared by **every** cloud Anycubic on the account - the broker allows one per account **and device type**. It signs in as `web`, so Tiger Studio and the slicer (`pcf`) stay connected beside it. Slots are read and set with the LAN's own `getInfo` / `setInfo` publishes on this session - **not** with the REST orders Tiger Studio uses: a REST call is a second TLS session, and beside this one it ran the device out of memory. The email, token and the shared client certificate come from the account document, are held in **RAM only** (the NVS partition cannot store them), and are refilled by every sync. Never logged. |
| `net/legacy_tls_client.cpp` | A `WiFiClientSecure` that verifies against one given CA **with SHA-1 signatures allowed** and presents a client certificate - what Anycubic's broker needs and the stock client cannot do (it rejects SHA-1, and skips the client certificate when unverified). Used for that broker only; everything else stays on `net/tls.h`. |
| `filament_resolve.cpp` | Decides what a printer is sent for a spool - temperatures, material family, Creality material id, Bambu filament id, pressure advance, name - field by field from the TigerTag+ product endpoint, the chip, the material table, a default. **Pure**: no network, no Arduino, the endpoint's answer is handed in, so it is tested on a computer with injected answers. The chip never carries a printer's material id; only the endpoint and the table do. A plain TigerTag never gets the endpoint's answer considered, even if one is passed. |
| `product_api.cpp` | Fetches the product endpoint on a task, **started when a TigerTag+ is read** (for a Creality today), not when Send is pressed; Send waits only while that fetch is inside its 3 s budget. One cached answer, by product id. It asks main.cpp to stand background links down only if the heap was short of a handshake when it started: standing them down cost nothing during the request and 800-900 ms of loop AFTER it, while they dialled back. `/api/resolve` runs the whole resolution from query parameters without a spool and without sending. |
| `tigertag_cloud.cpp` | Its network calls are on a **mixed** regime, not a uniform one. The sync and the pairing start run on their own FreeRTOS tasks; `pairPoll()` and `signInWithCustomToken()` are called straight from the main loop and stall it for about a second each. Neither pattern is the rule, so check which one a call is on before adding another. |

### One board, three TLS talkers - and what it actually costs

The account sync, the firmware check and the reference-table update each open
their own `WiFiClientSecure`. Two at once is fine; **three is not** - the third
gets a refused connection. That is why the table update runs on its own clock
ninety seconds after boot rather than beside the update check, and skips while
either of the other two is talking. It was measured, as `HTTP -1` on every
attempt.

**Do not generalise that to printer sessions.** Those three verify against the
Arduino core's root CA bundle, and parsing it is most of what they cost. A
printer session is `setInsecure()` and is cheaper - but a TLS printer still
takes 40-48 KB of internal RAM against 2-6 KB for any other, and the device
holds about three TLS sessions before fragmentation stops the fourth. Every
measurement, and the load budget that enforces it (`printer_budget.h`), is in
[docs/CONNECTION-BUDGET.md](docs/CONNECTION-BUDGET.md). A one-off TLS request
beside three printer sessions gets room from the TLS stand-down in `main.cpp`,
not from the budget.

## Landmines

Each row is something the code does not say about itself, and that a session
already paid for. Read the row before editing what it names.

### Generated data

| Where | What you need to know |
|---|---|
| `tools/tigertag_db/gen_db.py` | **It refuses a label the panel cannot draw.** Every label is checked against the compiled font range before a byte is written, and the build stops on the first one outside it. Exactly two things are repaired instead of refused - a no-break space becomes a space, a superscript becomes its digit - and both are printed as warnings so the upstream defect stays visible. Adding a repair is a decision about what a brand name IS; see the comment above `NBSP` before making one. |

### Text on the screen

| Where | What you need to know |
|---|---|
| `i18n.cpp`, the `STR` table | **It is positional.** The `static_assert` checks the number of *rows* against the enum and nothing else. It does not check that a row has the right number of entries, that the languages sit in the enum's column order, or that no entry is empty. A language block one column out of place compiles cleanly and mistranslates that entire language. A row one entry short zero-fills the rest, and a NULL reaches `lv_label_set_text`. |
| `enum Lang` (`i18n.h`) and `LANG_SCHEMA` (`i18n.cpp`) | The chosen language is stored in NVS **as an index**. Reordering or removing an entry silently changes what a stored index means, and the device comes back up speaking something else. `LANG_SCHEMA` exists for exactly this: bump it in the same edit and the stale index is discarded instead of misread. |
| Any string or label that reaches the panel | The faces cover Latin-1 and Latin Extended-A, so accents draw — but **`0xA0` is excluded on purpose**, and everything above Extended-A is not, **except the Chinese characters the source already uses**: the faces carry a Noto Sans SC subset of exactly those (`scripts/cjk-chars.py`), so a Chinese string with one new character needs the faces regenerated before it can draw. LVGL draws a missing glyph as a blank box and logs nothing, so nothing fails until a user sees it; `check-ui-fonts.py` is what catches it first. This includes **data**: reference labels are validated against the same range at generation time, which is how two brand names carrying a no-break space were found. |

### LVGL and the screens

| Where | What you need to know |
|---|---|
| `ui/frame.cpp` vs `screen_setup.cpp::addBack()` | **Two different back affordances exist.** The header one is a 56 px button on `LV_EVENT_CLICKED`: a slight drag between press and release cancels it, which is what made going back feel unreliable on a touch panel. `addBack()` is a full-width strip on `LV_EVENT_PRESSED` with no pressed-state highlight, because the screen is gone before a highlight could render. Copy the wrong one and back becomes hard to hit again. |
| `ui/frame.cpp`, screen swap | `lv_scr_load(new)` comes **before** `lv_obj_del(old)`. Deleting first deletes the screen that is still active, and LVGL faults inside the next draw. |
| `battery.cpp` (is there a cell) | **The user says so.** There is no detection left, because none of it worked: the board has no sense line, the rail with an empty connector sits anywhere from 4.05 to 4.27 V depending on the board, and the charger's ripple - which a healthy cell damps - is not damped by a tired one. Measured on our two boards, the ripple test was wrong in both directions: one reported a battery it did not have, the other denied the pack it was running on. `battery::declare()` writes the answer to NVS (`bdecl`) and `present()` is that answer, full stop. Everything downstream - the percentage, the runtime, `battery_present` in the heartbeat - follows it. |
| `battery.cpp` (charging) | Charging is not a fact this board reports - there is no status line - so it is inferred from the SHAPE of the curve: a step of 5 mV at the pin between two readings is a cable moving, and over three minutes a rise of 3 mV means charging while it takes a fall of 6 to say otherwise. That asymmetry is deliberate: a nearly full cell on a charger is flat, and judged symmetrically it reads as a discharge. The charger's contribution to the voltage is measured from that same step and kept in NVS, because it is not a constant - it shrinks as the charger tapers, and a fixed value put a nearly full cell fifteen points low. |
| `battery.cpp` (the pin) | The ADC on GPIO5 measures the battery **rail**, not the battery, through a 200K/100K divider (so times three). On USB that rail is held up by the charger whether a cell is plugged in or not - which is why presence is declared rather than read, and charging is inferred from the curve rather than reported. |
| `ui/signal_level.h` | The dBm-to-arcs scale, header-only and free of LVGL so it can be compiled and run on a computer - which is how the hysteresis was checked, rather than by waiting for a signal to wobble at the right moment. It is written **twice**: here for the panel and as JavaScript in `net/portal_page.h` for the portal's network list. `scripts/check-signal-scale.py` fails when the two disagree. |
| `ui/lvgl_port.cpp` | LVGL runs in a task of its own, core 1, priority 2 - it draws and reads the touch panel while the main loop is blocked inside a socket, which is what a TLS handshake to a printer that is switched off does for 1.3 s. Two consequences. **LVGL is not reentrant**: every public function in `ui/` takes `lvgl_port::Lock`, and so does anything in `webcfg.cpp` that touches it. **Flags set from an LVGL event callback are set on that task** and read on the loop, so they are `volatile` - `s_tapped`, `s_back` and their kind. `lvgl_port::loop()` no longer pumps LVGL when the task is running; it yields, so a screen just built is on the glass before the loop moves on. |
| `ui/screen_home.cpp` | `show()` runs from the main loop on every iteration, so it must be idempotent. It guards on a cheap signature of everything it renders, and **anything that changes what is displayed must be inside that signature** — visibility was once outside it, so hiding a printer changed nothing on screen. Rebuilding unconditionally destroys rows under the user's finger and reads as a frozen device. |
| `ui/screen_home.cpp`, the two faces | One screen, two faces: `showMain()` draws the choice (printers or reader) and `show()` draws the printer list, into the SAME container and header. Each keeps its own redraw signature, so the face itself is in the test - without it a face whose signature had not changed since it was last shown declines to rebuild and the other face's rows stay on screen. `headerFace()` owns what the header shows: the account and Wi-Fi icons are on the choice only, because a chevron, a title and three icons do not fit across 240 px. |
| `ui/screen_read.cpp` | Reader mode, and NOT the NFC tester (`screen_settings.cpp::showReader`). This one answers "what is this spool"; the tester answers "what is on this chip", field by field, and keeps every id and the raw pages. Adding a field here is a decision about the first question, not a free addition. |
| `tigertag_cloud.cpp`, presence | The device's own document in the account, `users/{uid}/tigerspools/{mac}`. The identity, liveness and power field NAMES are shared with the TigerScale on purpose - Studio renders both from one template - so they are not renamed for local taste. `docs/PRESENCE.md` is the contract, including the Firestore rule the account needs before any of it is allowed. The document id is the Wi-Fi MAC and its format is frozen. |
| Anything that loads a screen outside the state machine | Every screen keeps an "already showing, do not rebuild" flag. Code that swaps screens out of band — the screenshot preview route does — must invalidate all of them, or each guarded screen believes it is still displayed and stops redrawing. The device then looks frozen while the web server answers normally. |
| `webcfg.cpp`, and the web server generally | The screenshot handler renders a preview screen, forces a repaint, and reads the `canvas` sprite. It is **not** on the same thread as the drawing any more - the interface has its own task (`lvgl_port`) - so every one of those touches `lvgl_port::Lock` first. The rule that replaced "same loop, therefore safe": anything outside the drawing task that calls into LVGL, or reads what LVGL paints, takes that lock. Miss one and the fault is a torn screenshot on a good day and a corrupted object tree on a bad one. |

### State, storage and the account

| Where | What you need to know |
|---|---|
| NVS printer keys, `main.cpp` | Keys are positional - `p{i}t/n/h/s/c/d/u/m/k/v/a`, eleven per printer - but **a printer is recognised by what it is, not where it sits**: `samePrinter()` in `tigertag_cloud.cpp` (type, serial with FlashForge's optional `SN` dropped, then address or mode). The import matches every printer to its stored entry that way and moves what the device owns - the switch `v`, a discovered host - with it. Anything else that reads or writes `p{i}*` must not assume position `i` is still the same machine after a sync; `printerIdx` is remapped by the import for that reason. `main.cpp` links notice a change of settings under them by `cfgSig()` and reconnect. |
| Wi-Fi association, `main.cpp` | **Never call `WiFi.begin()` directly** for the home network - call `staBegin()`. The driver's default scan stops at the first access point with the right name and caches that radio for good, so on a multi-AP network the device stays on whichever it heard first: measured at -79 dBm with the same network at -46 one room away. `staBegin()` erases the cached association and connects by signal; the setup portal's join sets the same scan and sort without erasing (the phone is on the device's own AP). `/api/scan?all=1` lists every radio the device hears, with BSSID and channel. |
| Account sync, `tigertag_cloud.cpp` | **The account owns** a printer's name, serial, access code and Anycubic fields; an empty account field keeps what the device had. **The host is shared:** LAN discovery (`reconcile()` in `main.cpp`) may correct a K2's address, and that correction stands only while the account keeps giving the address it gave last time - `p{i}a` remembers it. When the account says something new, it wins. Two documents for one printer are merged, newer `updatedAt` first (integer or Firestore timestamp; unreadable counts as oldest). A printer new to the device arrives switched off. |
| The two FreeRTOS tasks | `ttSync` (16 KB) and `ttPair` (12 KB) are the only threads in an otherwise single-loop firmware. They signal completion through bare `volatile bool`, and **there is no mutex anywhere in `firmware/src/`**. The sync task writes the `tigerspool` NVS namespace while the UI loop reads it through `loadCfg()`. Nothing serialises that. `loadCfg()` reads six string keys per printer in sequence, so a sync landing between two of them yields a printer whose host came from the new import and whose name came from the old — a row on the home screen that matches no printer that exists. **Open bug**, not an accepted design: [2026-09-03](docs/reviews/2026-09-03-concurrency-and-identity.md). |
| Factory reset, `main.cpp` | It must clear **all four** NVS namespaces, current and legacy: clearing only the current one leaves the legacy data, and the migration path restores the user's whole configuration on the next boot — a factory reset that quietly undoes itself. The list of four is written out **twice**, in `main.cpp` and in `webcfg.cpp`, with nothing tying them together. Add a namespace to one and the other reset silently stops being a reset. |
| The Firestore fetch, `tigertag_cloud.cpp` | The server-side `mask.fieldPaths` and the client-side `Filter` + `NestingLimit(40)` look redundant and are **independent**: the mask cuts bytes, the filter cuts nesting depth. Each is explained in a comment beside itself, forty lines from the other, so removing one because "we already filter" fails the other way — as `TooDeep`, or as a 47 KB body for one brand. |
| Every HTTPS call | All of them use `setInsecure()`: sign-in, refresh, pairing, Firestore. No certificate is verified anywhere, so anyone on the local network can read the TigerTag refresh token and the account credentials off the wire. Acceptable on a bench, and a release blocker. |

### Build and release

| Where | What you need to know |
|---|---|
| `platformio.ini`, flash settings | `memory_type` and `flash_mode` are a **per-board** fact, not a house rule. A sibling project mandating different values for a different board is not a precedent to copy: the wrong pair here produces a boot loop, or a board that never finds its PSRAM and dies in the first LVGL allocation. |
| Release assets, `boot_app0.bin` | Shipped by the Arduino core, not built here, and its path inside the package tree is not ours to depend on. Locate it; never hard-code it. A release that omits it produces a device that boots the wrong slot after its first OTA. |
| The documentation guards | They live inline in `.github/workflows/build.yml`, not in `scripts/`, so they cannot be run locally today. The GPIO6/7 one fires when a pin number and a signal name land on the same line: it cannot tell a wiring instruction from a description of itself, and has already failed on a document explaining what it checks. It also passes silently on an empty input set, and greps untracked build directories. A guard that cannot fail, or that fails on something correct, is one people learn to bypass. |

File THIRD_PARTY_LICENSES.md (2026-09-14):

# Third-party licenses

TigerSpool RFID is MIT-licensed ([LICENSE](LICENSE)). It builds on third-party
components that keep their own licenses.

> This page is kept in step with `lib_deps` in `firmware/platformio.ini` by
> hand. Nothing checks yet that the two agree - CI should, and does not.

## Dependencies

| Component | License | Used for |
|---|---|---|
| [arduino-esp32](https://github.com/espressif/arduino-esp32) | LGPL-2.1 | Framework: Wi-Fi, NVS, web server, DNS, mDNS, TLS, OTA |
| [ESP-IDF](https://github.com/espressif/esp-idf) | Apache-2.0 | Underlying SDK |
| [LovyanGFX](https://github.com/lovyan03/LovyanGFX) | FreeBSD (2-clause BSD) | Display and touch driver |
| [LVGL](https://github.com/lvgl/lvgl) | MIT | UI toolkit: every screen |
| [ArduinoJson](https://github.com/bblanchon/ArduinoJson) | MIT | Parsing printer reports, building commands |
| [WebSockets](https://github.com/Links2004/arduinoWebSockets) | LGPL-2.1 | Creality and Snapmaker transports |
| [PubSubClient](https://github.com/knolleary/pubsubclient) | MIT | MQTT transport: Bambu Lab, Elegoo, Anycubic |
| [PN532 / PN532_HSU](https://github.com/Seeed-Studio/PN532) (Seeed / elechouse) | Apache-2.0 | NFC reader driver — **vendored and patched**, see below |
| [ESP Web Tools](https://github.com/esphome/esp-web-tools) | Apache-2.0 | Browser installer |
| [mbedTLS](https://github.com/Mbed-TLS/mbedtls) | Apache-2.0 | TLS, bundled with ESP-IDF |
| [Font Awesome Free](https://fontawesome.com) | Fonts under SIL OFL 1.1, icon artwork under CC BY 4.0 | Every `LV_SYMBOL_*` glyph, plus the sun on the Display row, extracted into the `firmware/src/ui/font_ui_*.c` faces by `scripts/make-ui-font.sh`. The outlines come from the copy shipped inside the pinned LVGL package, so the library version pins them; no font file is committed. `lv_font_conv` extracts outlines from the font, so it is the OFL that governs what is compiled in. |
| [Montserrat](https://github.com/JulietaUla/Montserrat) | SIL OFL 1.1 | The UI typeface. Latin-1 and Latin Extended-A subsets extracted into `firmware/src/ui/font_ui_*.c` by `scripts/make-ui-font.sh`: the Medium weight from the copy shipped inside the pinned LVGL package, SemiBold from the typeface's own repository, cached outside the tree. No font file is committed. |
| [Noto Sans SC](https://github.com/notofonts/noto-cjk) | SIL OFL 1.1 | The Chinese interface. Medium weight, release tag `Sans2.004`: only the Han characters and CJK punctuation our own translations use - listed by `scripts/cjk-chars.py` - are merged into the `firmware/src/ui/font_ui_*.c` faces by `scripts/make-ui-font.sh`, not the face. Fetched and cached outside the tree; no font file is committed. |
| [JetBrains Mono](https://github.com/JetBrains/JetBrainsMono) | SIL OFL 1.1 | The NFC tester's page dump, which has to line up in columns a proportional face cannot give. Eighteen glyphs - space, 0-9, A-F and x - extracted into `firmware/src/ui/font_ui_mono_16.c` by `scripts/make-ui-font.sh`, fetched from the project's own repository and cached outside the tree. No font file is committed. |

## The vendored PN532 driver

`firmware/lib/PN532/` will contain a **modified copy** of the Seeed/elechouse
PN532 library, kept in-tree rather than pulled from the registry.

**Why it is vendored:** the driver needs patches that are specific to this
hardware and cannot be applied to an upstream dependency — most importantly, a
wake-up preamble before every command, without which these modules answer once
after boot and then never again. See
[docs/MIGRATION.md](docs/MIGRATION.md#the-vendored-pn532-library).

**Obligations:** it is Apache-2.0. The upstream copyright notice, license text
and `NOTICE` are preserved in the vendored directory, and the modifications are
marked as such. Its own README will state clearly that it is modified, what was
changed, and why.

## LGPL components

Two dependencies are LGPL-2.1 (arduino-esp32 and the WebSockets
library). They are statically linked into the firmware image, which the LGPL
permits provided the user can relink against a modified version of the library.

That is satisfied here in the strongest way available: **the entire build is open
source.** The firmware source, the exact dependency versions and the build
configuration are in this repository, and CI reproduces the published binaries
from them. Anyone can substitute a modified library and rebuild.

## Trademarks

The **TigerTag** and **TigerSpool** names and logos are trademarks of the
TigerTag Project and are not covered by the MIT license. See
[TRADEMARK.md](TRADEMARK.md).

Bambu Lab, Creality, FlashForge, Snapmaker, Elegoo and Anycubic are trademarks of
their respective owners. TigerSpool is not affiliated with, endorsed by, or
sponsored by any of them. Their printer protocols are supported through
independent reverse-engineering, and their names are used only to state which
printers this project works with.

## Corrections

If a license here is wrong, or a component is missing, open an issue — we will
fix it.

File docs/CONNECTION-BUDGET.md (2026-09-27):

# The connection budget

How many printers one TigerSpool can hold open at once, how that is decided,
and every measurement it rests on. Written to be come back to: when a new brand
is added, when a number looks wrong, or when the budget is tuned per use case.

The code is [`firmware/src/printer_budget.h`](../firmware/src/printer_budget.h).
If this document and that file ever disagree, the file is what runs - fix
whichever is wrong, in the same change.

---

## The idea: load slots, like seats on a bus

The limit was never a **number** of printers. It is **internal RAM**, and how
much of it a printer's connection takes depends almost entirely on one thing:
whether it speaks TLS. A Bambu or an Anycubic costs 40-48 KB; everything else
costs 2-6 KB. Ten Elegoos fit where three Bambus do not, so a limit written as
"N printers" would be wrong for nearly every account.

So every printer takes the **load slots** its connection actually costs, and
the device has a fixed number of them. **One load slot is one kilobyte of
internal RAM.**

> **"Load slot", never plain "slot".** In this codebase a *slot* is a place a
> spool sits - an AMS tray, a station bay (`SlotState`, `slotCount`). The two
> must not be confused in code, in logs or in conversation.

A printer is refused at the moment somebody **switches it on**, when they can
see why - not later, as a dot that stays red with no explanation.

---

## The numbers

### The budget: 160 load slots

| | |
|---|---|
| Internal RAM free at boot, before any printer | **198 - 203 KB** (varies between boots) |
| Survival floor - below this the device closes a link to stay alive | **32 KB** |
| Usable for printers | **~166 KB** |
| **Budget** | **160 load slots** |
| Reserve kept for what the model does not count | **~6 KB** |

The reserve covers what the budget does not model: a web page being served, a
JSON document being parsed, a screen being built.

**Why 160 and not 200.** 200 is roughly what is free before anything runs, but
the device cannot spend all of it: 32 KB is the survival floor below which
`main.cpp` starts closing background links, and a few more are needed for the
device's own work. That leaves ~166.

**Why 160 and not 166.** It was 150 at first, keeping a 16 KB reserve. It was
raised to 160 deliberately, trading ten kilobytes of that reserve for room for
one more printer - a LAN Bambu beside a full bench, or several light ones.

**Why the thin reserve is safe.** The budget is not what stops a crash. The
32 KB floor and the *sustained* low-memory closer in `main.cpp` are: if free
memory stays under the floor for three seconds, the last background link is
closed. At worst a peak costs a printer its connection for a moment. The budget
exists to make the choice visible and predictable, not to guard the heap.

### Load slots per printer

Each is the **worst cost measured** for that connection, rounded up to the next
kilobyte. The margin is not spread across the brands - it lives once, in the
reserve above.

| Printer | Measured (worst of 5 passes) | Load slots | What the cost is |
|---|---|---|---|
| **First Bambu Lab in cloud mode** | 48.5 KB | **50** | opens the TLS session every cloud Bambu on the account shares |
| **Each further Bambu Lab in cloud mode** | 3.6 KB | **4** | only subscribes to the shared session |
| **Bambu Lab in LAN mode** | *not measured* | **50** | its own broker, its own TLS session |
| **Anycubic** | 40.4 KB | **41** | TLS |
| **First Anycubic in cloud mode** | 51 KB | **50** | opens the TLS session, with a client certificate, every cloud Anycubic on the account shares |
| **Each further Anycubic in cloud mode** | *not measured* ([#19](https://github.com/TigerTag-Project/TigerSpool-RFID/issues/19)) | **4** | only subscribes to the shared session - charged as a further cloud Bambu |
| **Creality** | 5.6 KB | **6** | WebSocket |
| **Snapmaker** | 4.9 KB | **5** | WebSocket |
| **Elegoo** | 2.5 KB | **3** | plain MQTT, no TLS |
| **FlashForge** | 2.0 KB | **2** | HTTP; nothing held between requests |

**The one assumption left: Bambu in LAN mode.** Both LAN Bambus on the bench
were switched off at every measurement. It is charged 50 because it opens
exactly what a cloud printer opens - the same TLS client against a broker - but
that is reasoning, not a reading. The first bench with one switched on should
replace it.

### Per connection, not per printer

Only the cloud printers depend on what else is open - Bambu and Anycubic
alike, each with a session of its own brand. Every Bambu in cloud mode on
one account talks to the same regional broker with the same credentials, so
they share **one** TLS session ([`bambu_cloud.cpp`](../firmware/src/bambu_cloud.cpp)):
the first pays for it, each further one is a subscription on it.

| Bench example | Load slots |
|---|---|
| Three cloud Bambus | 50 + 4 + 4 = **58** |
| The same three before the session was shared | ~141 KB measured |

Every other printer's cost is its own and does not depend on the others.

### Worked example: the bench account

| Printer | Load slots |
|---|---|
| Creality Ender-3 | 6 |
| Bambu A1 (first cloud) | 50 |
| Bambu X1C (further cloud) | 4 |
| Snapmaker U1 | 5 |
| Elegoo Centauri Carbon 2 | 3 |
| Anycubic Kobra X | 41 |
| **Total** | **109 of 160 - shown as 68%** |

Measured the same evening: those six printers took **103.2 KB**. The model is
6 KB on the cautious side for this set.

---

## What the user sees

A bar in **Settings > Printers** and on the first-boot **Choose printers**
screen, above the list, labelled **Load** with a **percentage** - "68%", not
"109 / 160". Load slots are how the device counts; a person needs to know how
full it is, and a percentage says that without knowing what the 160 is.

- The accent colour while there is room, **orange from 85%**.
- A switch that would overflow the budget **does not move**, the bar turns
  **red** and the label reads **"Not enough room"** for two and a half seconds.
- Switching a printer **off** is always allowed.

The raw counts are in the serial log, in the form
`[budget] '<printer>' refused: <total it would reach> of 160 load slots`.

---

## What the model does not see

**Fragmentation.** A new TLS session needs one contiguous piece of about 40 KB,
and after three TLS sessions the largest free block has been measured as low as
18 KB - while the total said there was plenty. The budget adds totals and does
not see that shape.

Today the two agree, by arithmetic rather than by design: 160 load slots caps
TLS sessions at three, which is also the ceiling observed. The cheapest four -
one cloud Bambu and three Anycubics - come to 173, over the budget before a
single light printer.

A **one-off** TLS request - an account sync, an update check - is kept possible
by a separate mechanism, the TLS stand-down in `main.cpp`: background links step
aside for the second or two the request needs and come straight back. The
budget does not provide for those.

**The link limit.** Independently of memory, the code holds at most ten
links (`MAX_LINKS` in `main.cpp`). A printer that is switched on but powered off
still holds one while it retries. With the shared cloud session, the bench
account reached **ten links with 133 KB still free** - for this account the
binding limit is now the link count, not the RAM.

---

## How the numbers were measured

`/api/memtest` on the device's web server. It closes every link, holds the
account sync off, and opens printers **one at a time**, reading internal RAM
and PSRAM after each one has been up for ten settled seconds. The report goes
to the serial console.

    http://<device>/api/memtest          the printers switched on
    http://<device>/api/memtest?all=1    every printer on the account

Why it had to be built: numbers taken in normal running were not facts about
any printer. Links opened in groups and an account sync allocated a TLS session
in the middle, so the per-link figures added up to 193 KB against 135 KB
measured on the whole.

**Why the MQTT buffers are not in the table.** This framework is compiled with
`CONFIG_SPIRAM_USE_MALLOC` and a 4 KB internal threshold, so every allocation
over 4 KB - the 50 KB Bambu receive buffer included - lands in PSRAM, of which
8 MB is idle. What stays in internal RAM is mbedTLS, pinned there by
`CONFIG_MBEDTLS_INTERNAL_MEM_ALLOC`. That is why a printer's cost is, to within
a few kilobytes, whether it speaks TLS.

Five passes, 2026-09-10, on one Waveshare ESP32-S3-Touch-LCD-2:

| Pass | Setup | Notes |
|---|---|---|
| 1 | per-printer sessions, active printers | the first clean numbers |
| 2 | per-printer sessions, whole account | three TLS sessions fit, a fourth did not |
| 3 | shared cloud session, active printers | second cloud Bambu 3.2 KB |
| 4 | shared cloud session, active printers | repeat, evening |
| 5 | shared cloud session, whole account | three cloud Bambus on one session; stopped on link slots, not RAM |

---

## When to revisit

- **A new brand**: measure it with `/api/memtest` and add its worst case to the
  table and to `loadSlotsFor()`. Do not estimate.
- **A LAN Bambu is switched on at the bench**: measure it and replace the
  assumed 50.
- **The framework is updated**: re-run all five passes. A change to the
  PSRAM malloc threshold or to where mbedTLS allocates changes every number.
- **Tuning per use case** - planned: the numbers here are the floor any tuning
  starts from.
- **More than three TLS printers are wanted**: see
  [ROADMAP.md](ROADMAP.md#more-tls-printers-at-once). The two ways past it are
  mbedTLS in PSRAM, or sharing more sessions.

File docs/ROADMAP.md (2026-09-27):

# Roadmap

What is deliberately not done yet, why, and what has to be decided before it
can be. Everything here is a decision that was taken, not a thing forgotten —
an item leaves this file by being built or by being ruled out, never by
quietly rotting.

Anything already broken lives in [reviews/](reviews/), not here.

---

## The account: a heartbeat

**The device never writes to the account.** It reads printers, the profile and
the display name; there is no write path at all. So nothing in Tiger Studio can
show which TigerSpools exist, which are switched on, or when one was last seen.

The TigerScale does this with a periodic `PATCH` of telemetry it alone knows —
battery, charging state, Wi-Fi signal, mDNS hostname — every 30 s with the
screen lit, every 5 min with it dark, and forced immediately on an event a
person causes and then watches.

The TigerSpool now measures the same things locally (`battery.cpp`, and
`/api/batt` returns them as JSON), so what is missing is the write path and the
decision below, not the data.

**Deferred on purpose.** It is not urgent, and it is the piece most likely to
be built wrong in a hurry.

**Decide before writing the first line: who owns each field.** This is the
sibling project's strongest advice on the subject and the reason it has no
write conflicts at all — the scale never writes a field Tiger Studio owns. It
*reads* `displayName` and never writes it. Once two writers share one field, no
arbitration rule is a good one: not last-write-wins, not merge, not a timestamp.
Partition the fields first and the conflict never exists.

**Ask the TigerScale agent for the specifics when this is picked up:** exactly
what it writes, to which document path, on what cadence, what forces an
immediate write, and how a failed write is handled. Its answer to the previous
question is in `_internal/TIGERSCALE-CLOUD-ANSWERS.md` and covers the shape;
the exact field list and paths were not asked for and should be.

Known limit to inherit knowingly: the scale has **no offline queue**. A failed
write is lost and the next one carries current values. That is right for
telemetry, where the newest value replaces the last — and wrong for anything
that must not be lost. If a TigerSpool ever writes an event rather than a state
("this spool went to this printer"), it needs a queue, and a queue does not get
added afterwards without rethinking the rest.

## The account: being told about changes

Nothing tells the device that an account changed. It polls every five minutes,
and refreshes when the printer picker opens — which covers the moment that
matters.

**Blocked on a question the firmware cannot answer: who writes the signal, and
when?** Every mechanism — a Firestore command queue, a realtime-database node
streamed over SSE — is inert until something in the backend writes to it. Half
of this feature lives outside this repository.

Worth building only when a specific need is named that genuinely cannot wait
five minutes. The test: *which screen would somebody sit and watch, waiting for
this to change?* On a scale that is the weight, and it does not come from the
network. On a spool reader there is no such screen yet.

## Firmware signing

The update connection is verified against the root store, so a device knows who
it is talking to — but not who produced the image. See
[OTA.md](OTA.md) for the reasoning and the condition for changing it. The key
must never touch CI, which is the part that makes this more than an afternoon.

## Accented text in the five languages that are not French

Done for French, and the font no longer stands in the way of the rest. The UI
faces are generated by `scripts/make-ui-font.sh` over
`0x20-0x7F,0xA1-0x17F,0x2022`, which covers German, Spanish, Italian,
Portuguese and Polish as completely as it covers French - the translations for
those five are simply still written without their diacritics.

What is left is a translation pass, not a font problem, and it wants somebody
who reads the language. Restoring a diacritic in the wrong place is worse than
leaving it out: a missing accent reads as a device that could not draw one, a
wrong one reads as a device that does not know the language. Polish in
particular is not a job for a search and replace.

## More TLS printers at once

How many printers fit today, and every number behind that, is in
[CONNECTION-BUDGET.md](CONNECTION-BUDGET.md): the device refuses a printer that
would overflow a budget of 160 load slots, and a TLS printer takes 41-50 of
them. This entry is about raising that ceiling.

**Measured, and it overturns what this entry used to say.** It was titled
"Move the MQTT buffers to PSRAM" and proposed vendoring PubSubClient to do it.
They are already there. This framework is built with `CONFIG_SPIRAM_USE_MALLOC`
and `CONFIG_SPIRAM_MALLOC_ALWAYSINTERNAL 4096`, so every allocation over 4 KB -
the 50 KB Bambu buffer, the 16 KB Anycubic one - goes to PSRAM without being
asked. `/api/memtest` shows it directly: the buffer lands in the PSRAM column.

What sits in internal RAM is **mbedTLS**, which the same config pins there
(`CONFIG_MBEDTLS_INTERNAL_MEM_ALLOC`). `/api/memtest`, every link closed, the
account sync held off, printers opened one at a time and read after ten settled
seconds:

```
baseline, 0 links   free 202124   largest 61428
creality            3856  internal       0 psram
bambu (background) 43940  internal    8208 psram
bambu (on screen)  47756  internal   51216 psram
snapmaker           4884  internal       0 psram
elegoo              2128  internal    8208 psram
anycubic           39432  internal   16400 psram
done, 6 links       free  60128   largest 18420   psram 8.1 MB free
```

**So a printer costs one thing: whether it speaks TLS.** A WebSocket or plain
MQTT printer is 2 to 5 KB and ten of them fit comfortably. A TLS printer - Bambu,
Anycubic - is 40 to 48 KB, and the device holds about **three**. Not by total
memory alone: the largest free block falls from 61 KB to 18 KB across those
three, and a new TLS session needs one piece that size. Fragmentation is what
stops the fourth, and it stops it before the total would.

**The two ways past it, neither small:**

1. **Put mbedTLS in PSRAM.** `CONFIG_MBEDTLS_EXTERNAL_MEM_ALLOC`. It is an
   sdkconfig option, and the Arduino core here is precompiled with its sdkconfig
   fixed - so it means building Arduino as an ESP-IDF component, a change of
   build system. It would take TLS from 40 KB internal to near nothing and lift
   the limit to whatever the ten-link cap allows. PSRAM is slower, and a TLS
   handshake is CPU-bound, so connects would get slower; how much is a
   measurement to make, not a guess.
2. ~~**Share one TLS session between Bambu printers on the same cloud
   broker.**~~ **Built in 1.46.0** (`bambu_cloud.cpp`): every cloud Bambu on
   an account rides one session, routed by the serial in each report's topic,
   and a further one costs 3.6 KB instead of ~48. LAN-mode Bambus each have
   their own broker and cannot share, and neither can Anycubic, so option 1 is
   what remains for those.

**What this entry no longer proposes:** vendoring PubSubClient, shrinking the
Bambu buffer after connect, or sizing it by role for the sake of internal RAM.
All three would move PSRAM around, of which 8 MB is idle.

### The 24-AMS case is simpler than it looked

A Bambu can chain up to 24 AMS units - 96 trays plus the external spool. Rare.
It is not a memory problem, because the report buffer is in PSRAM and PSRAM is
not short. It is a data-model problem: `BMAX` is 17, labels run A to D, and a
report that size would exceed the 50 KB buffer and be dropped whole, so the
screen would show nothing rather than something wrong. The fix is a buffer
sized for it (in PSRAM, free) and a slot array sized from the topology the
first report describes - "A1" to "X4" is twenty-four letters, exactly the
alphabet's usable run.

The periodic pushall is gone (81 KB a minute for trays that had not moved), so
such a machine costs one large report at connect and 1.2 KB increments after.

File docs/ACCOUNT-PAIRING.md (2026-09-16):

# Linking a TigerTag account

How a device with no keyboard gets signed in — and why that sign-in is what makes
the whole product work.

---

## Why the device signs in at all

Because this is where TigerSpool stops being another spool scanner.

Your printers are already in your TigerTag account: you added them in
**[Tiger Studio](https://github.com/TigerTag-Project/TigerTag-Studio-Manager)**,
on a computer, with a keyboard, once. Names, addresses, serial numbers, access
codes.

When TigerSpool signs into that account it reads `users/{uid}/printers/*` and
configures itself. **The user never types a printer's IP address or access code
into a 2.0" touchscreen, because they never have to type it at all.** Add a
printer to your account next month and TigerSpool picks it up on its own, on its
next sync.

The account is not a nice-to-have wrapped around a local product. It is the
product's core, and the architecture assumes it.

---

## Two ways in, both without a device keyboard

Same as [TigerScale](https://github.com/TigerTag-Project/Tiger-Scale-V3). Users
arrive with accounts created either way, so both paths stay.

### 1. Email and password — typed on the phone

Reached from the configuration web page, at `http://tigerspool-xxxx.local` on the LAN
or through the setup portal. The user types their email and password **on their
phone's keyboard**, with their password manager available, on a page the device
serves.

The device exchanges them for a session and stores the refresh token. It never
stores the password.

### 2. Google — a QR code on the device screen

Accounts created with Google have **no password to type**, so there is nothing a
form can ask for. These sign in by scanning a QR code shown on the device itself.

---

## The QR pairing flow

```
  TigerSpool                    TigerTag cloud                  owner's phone
      |                                |                              |
      |--- POST pair/start ----------->|                              |
      |<-- code + verify_url + poll_token                             |
      |                                |                              |
  [ draws a QR of verify_url ]         |        <---- scans it -------|
  [ prints the code beneath it ]       |                              |
      |                                |<--- opens verify_url --------|
      |                                |     (signs in with Google
      |                                |      if not already)
      |                                |<--- approves ----------------|
      |                                |  [ mints a custom token ]    |
      |                                |                              |
      |--- POST pair/poll ------------>|                              |
      |<-- status: approved, custom_token                             |
      |                                |                              |
      |--- signInWithCustomToken ----->|  (Identity Toolkit)          |
      |<-- idToken + refreshToken                                     |
      |                                |                              |
  [ stores the refresh token, reads the account's printers ]
```

**The URL in the QR already carries the code.** The user scans something that is
physically in front of them and taps approve on a phone where they are usually
already signed in. Nothing is read off one screen and typed into another.

### Why not RFC 8628

[RFC 8628](https://datatracker.ietf.org/doc/html/rfc8628) is the OAuth device
authorization grant, and it exists for exactly this shape of device. It was
examined and rejected — the same conclusion, for the same reasons, as
[TigerScale V3](https://github.com/TigerTag-Project/Tiger-Scale-V3/blob/main/docs/ACCOUNT-PAIRING.md):

- **The QR cannot carry the code.** Google's device-code response has no
  `verification_uri_complete`. It returns a bare URL and an eight-character code
  the user must retype. The best achievable experience becomes "scan this, then
  copy a code across from a screen 40 cm away" — which is the friction this whole
  design exists to remove.
- **Polling requires a `client_secret`**, which a public firmware binary must not
  carry. It could be provisioned at runtime, but that is machinery in service of
  a flow that is worse anyway.
- **It authenticates against Google only.** Apple, or any provider added later,
  would each need a separate path.

Pairing through TigerTag's own cloud has none of those properties, because both
ends belong to the project.

### Why the code and the poll token are different secrets

The **code** is short because a human may read it aloud or type it. The **poll
token** is long because whoever holds it receives the credential.

If one value did both jobs, anyone who glimpsed the screen from across the room
could poll for the token themselves. They are separate on purpose.

### What the approval page must show

The page reached by the QR has to name **which device is asking** — its name and
the last four of its MAC address — and **which account** it would be linked to.

The risk of a user approving someone else's pairing code is low here, because
they are looking at the physical screen the QR came from. But a page that says
only "Approve?" trains people to approve anything, and that habit is the actual
vulnerability.

---

## On-device screens

| Screen | Shows |
|---|---|
| **Account** | Signed-in email, or an invitation to link an account. |
| **Pairing** | The QR code, large. Under it the address from `verify_url` - scheme, query and code stripped off, drawn at the largest face that fits it on one line - then the short code, then a countdown to expiry. Nothing here is written into the firmware: change `verify_url` and the screen follows. |
| **Approved** | Confirmation and the account's email, then straight to importing printers. |
| **Denied** | Says so, and offers a fresh code. Never a bare error. |
| **Expired** | No screen: the countdown runs out and the device returns to the sign-in choice on its own. Ten minutes of nobody approving is not a failure to report, and choosing Google again fetches a fresh code. |

The pairing flow **must be reachable from the device screen**, not only from the
web page. A user standing in front of the box with a phone in their hand should
not have to find a URL on another device first.

---

## Endpoints

These are the endpoints **TigerScale V3 actually calls in shipped firmware**, and
the prototype calls the same ones. They are the deployed, working surface.

| | |
|---|---|
| Start | `POST https://us-central1-tigertag-connect.cloudfunctions.net/pairStart` |
| Poll | `POST https://us-central1-tigertag-connect.cloudfunctions.net/pairPoll` |
| Sign in | `POST https://identitytoolkit.googleapis.com/v1/accounts:signInWithCustomToken` |
| Refresh | `POST https://securetoken.googleapis.com/v1/token` |
| Printers | Firestore REST, `users/{uid}/printers/*` |

> **On `/api/device/pair/*`.** TigerScale V3's own documentation describes a
> first-party API path rather than raw Cloud Function URLs. Its firmware does not
> use it — the shipped code hardcodes the two Cloud Function URLs above. Treat
> `/api/device/pair/*` as an intended future surface, not something to code
> against today. If it is ever built, moving to it is a two-constant change.

### `pair/start`

Unauthenticated: the device has no identity yet. That is what the rate limit and
the short expiry are for.

Request:

```json
{ "device": "tigerspool-a1b2", "model": "TigerSpool RFID", "kind": "bridge", "fw": "1.0.0" }
```

Response:

```json
{
  "code":       "K7QF-3M2P",
  "verify_url": "https://tigersystem.io/pair/K7QF-3M2P",
  "poll_token": "<32 bytes, base64url>",
  "expires_in": 600,
  "interval":   5
}
```

### `pair/poll`

```json
{ "poll_token": "<the value from start>" }
```

| Response | Meaning |
|---|---|
| `{"status":"pending"}` | Nobody has approved yet. Poll again after `interval` seconds. |
| `{"status":"approved","custom_token":"<jwt>","email":"…"}` | Sign in with it. Single use — the record is consumed. |
| `{"status":"denied"}` | The owner refused. Stop and say so on screen. |
| `{"status":"expired"}` | Older than `expires_in`. Start again with a fresh code. The device does not wait for this: it stops polling and leaves the screen when its own countdown reaches zero. |

### Requirements on the cloud side

- Rate-limit `start` per IP and `poll` per token; reject a poll faster than
  `interval` with the same back-off the OAuth device flow uses.
- Codes are single-use and expire in ten minutes - the same ten the device
  counts down on screen.
- `verify_url` is what the QR carries and what the screen prints, so it must be
  an address a person can also type. `https://tigersystem.io/pair/<CODE>` and
  `https://tigertag-cdn.web.app/pair.html?c=<CODE>` both answer today; the
  device strips the code either way and prints the address alone.
- Store the pending record keyed by a **hash** of the poll token, not the token.

---

## Importing printers

Once signed in, the device reads the account's printers and writes them to NVS
as `p0`, `p1`, … - up to `MAX_PRINTERS`, 24.

**What it can reach.** Printers on the LAN are imported, and so are Bambu Lab
printers in cloud mode, read-only: the device reads their slots through Bambu's
broker but cannot write to them. A cloud-only printer of any other brand is
skipped, with the reason in the log, rather than imported as if it were on the
network.

**Sync is periodic and non-blocking.** The account is re-read every few minutes
on a background task, whatever screen is up. The result is applied only on the
printer screens - never mid-scan, and never under the slot grid someone is
using.

**The account is the source of truth for what it holds.** Name, serial, access
code and address are taken from the account at every sync, so a printer that
moves or gets a new code in Tiger Studio is followed. Two exceptions, both
deliberate: a field the account leaves empty keeps the device's value rather
than being blanked, and a K2 address found by LAN discovery stands while the
account keeps giving the address it gave before. What the account does not
hold - which printers are switched on - belongs to the device.

**A printer is recognised by its serial, not its position.** Adding or removing
a printer in the account does not hand anyone else's address, code or switch to
the printers after it, and two documents for one printer are merged, the newer
winning. The rules are `samePrinter()` in `tigertag_cloud.cpp`.

---

## Security

**The refresh token is a long-lived credential to someone's account.** It is
stored in **encrypted NVS**, never in plaintext flash. See [SECURITY.md](../SECURITY.md).

**TLS certificates must be validated.** The prototype disables verification on
every HTTPS call, which was acceptable on a bench and is not acceptable shipped.
A pinned root CA bundle, and a plan for rotating it, is required before release.
This is tracked as a release blocker.

**Signing out must actually revoke.** "Forget this device" has to clear the local
session *and* be reflected in the account, so that a user who sells or loses a
device can cut it off from a phone. A local-only wipe is not a revocation.

**The device never signs in to a printer vendor's cloud.** Where a vendor session
is needed — Bambu Lab's, for instance — Tiger Studio obtains it and the account
carries it. The firmware only consumes it.

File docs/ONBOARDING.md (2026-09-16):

# Onboarding

The user's journey, screen by screen, from a sealed box to a scanned spool.

**The target:** a person who has never flashed a microcontroller gets to their
first successful scan without reading anything, without a keyboard on the device,
and without knowing what an IP address is.

---

## Before the box

The user has already done one thing on a computer: added their printers to
**[Tiger Studio](https://github.com/TigerTag-Project/TigerTag-Studio-Manager)**.
That is where a keyboard exists and where typing an access code is reasonable.

Everything below assumes that. TigerSpool's job is to make the rest require no
typing at all.

---

## 1 · Install the firmware

**Browser, USB cable, one click.** The web installer at
`https://tigertag-project.github.io/TigerSpool-RFID/` uses ESP Web Tools in
Chrome or Edge: plug the board in, pick the serial port, click Install.

No PlatformIO. No Arduino IDE. No command line. See [installer/](../installer/).

*(Anyone who already owns an assembled TigerSpool skips this entirely — it ships
flashed and updates itself. See [OTA.md](OTA.md).)*

---

## 2 · First boot — language

```
        ┌────────────────────────────┐
        │   Choose your language     │
        │                            │
        │   ┌──────────────────┐     │
        │   │     English      │     │
        │   ├──────────────────┤     │
        │   │     Français     │     │
        │   ├──────────────────┤     │
        │   │     Deutsch      │     │
        │   ├──────────────────┤     │
        │   │     Español      │     │
        │   └──────────────────┘     │
        │          ●  ○              │
        └────────────────────────────┘
```

Asked once, remembered. It comes first because every screen after it is written
in the language chosen here — including the error messages.

---

## 3 · Wi-Fi

```
        ┌────────────────────────────┐
        │  Wi-Fi setup               │
        │                            │
        │      ███  ██ ████ ██       │
        │      █ ██████  ████        │
        │      ████ ██ ███  █        │
        │      ██  ████ █████        │
        │                            │
        │  Scan the QR code          │
        │  camera, or join           │
        │                            │
        │   TigerSpool-Setup-XXXX    │
        │                            │
        │  Waiting for a phone…      │
        └────────────────────────────┘
```

1. The user points their phone camera at the QR. It offers *"Join TigerSpool-Setup-XXXX"*.
2. One tap and the phone is on the box's network.
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

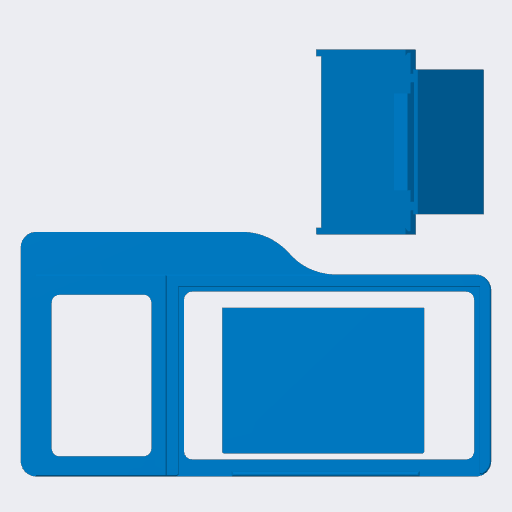
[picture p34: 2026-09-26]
Model3D/2.Creality/K2-K2Pro/Images/tigerspool-k2-bambu-studio-top.png

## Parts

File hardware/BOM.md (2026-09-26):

# Bill of materials

Everything needed to build one TigerSpool. **The electronics are identical for
every printer brand** — only the printed shell changes ([Model3D/](../Model3D/)).

> **Prices are indicative** and were not re-checked at the time of writing.
>
> Some links here are Amazon affiliate links: buying through them pays the
> project a small commission at no cost to you. Nothing on this list is chosen
> because it is affiliated — the parts came first, and any equivalent module
> works. Where a link is missing, the part is named precisely enough to search
> for.

## Three things to buy

| # | Part | Why this one | ~Price |
|---|---|---|---|
| 1 | **[Waveshare ESP32-S3 2inch Capacitive Touch Display Development Board](https://link.amazon/B06RoLfDi)** — 240×320 IPS, LX7 dual-core to 240 MHz, Wi-Fi and Bluetooth. (Listed with an OV5640 camera header; the camera is not included and TigerSpool does not use it.) | 2.0" 240×320 IPS with CST816S capacitive touch, ESP32-S3**R8**, 16 MB flash, 8 MB octal PSRAM. The screen, the touch panel and the MCU are one board — there is no separate display to wire. The 16 MB is what makes two OTA slots comfortable. | ~25 € |
| 2 | **PN532 NFC module**, V3 breakout with DIP switches — e.g. [this kit](https://link.amazon/B0iJgHVtP) | Reads the NTAG21x chips TigerTag uses. It **must** support **HSU/UART** mode; the DIP-switch V3 boards do, and both switches go to `0` / OFF. A two-pack costs barely more than one, and the spare settles "is it the module or my wiring?" in a minute. | ~9 € the pair |
| 3 | **A USB-A to USB-C cable that carries data** — e.g. [this one](https://link.amazon/B00Xg3WT4) | Powers the board and flashes it. **Speed is irrelevant**: the ESP32-S3's native USB is full-speed, so any USB 2.0 data cable is enough. What matters is that it carries data at all. | ~5-10 € |

Plus a **3D-printed case** from [Model3D/](../Model3D/), about 30 g of filament.

## Two things worth adding

Neither is needed to build a working TigerSpool, and both earn their place next
to a printer.

| Part | Why | ~Price |
|---|---|---|
| **[Magnetic USB connector](https://link.amazon/B0bWVIBa0)** | The USB port is the one thing on this box that gets handled - a spool goes past it every day. A magnetic tip stays in the socket and the cable lets go instead of the connector. | ~10 € |
| **[3.7 V 1000 mAh LiPo cell, PH1.25 connector, with protection](https://link.amazon/B0fL0jjf3)** | The board charges it over USB and runs from it when the cable is out, so the box can be carried to a printer to write a spool and brought back. Optional, and **you declare it**: the board cannot tell whether a cell is on its connector, so once one is fitted, switch it on in **Settings › Battery**. The level, the state and the time left appear from then on. | ~10 € for four |

**Check the polarity before plugging a cell in.** The connector is not keyed
against a cell wired the other way round, and the board has no protection
against it. The battery connector is `J4`, marked on the board.

**The four jumper wires come with the PN532** — 3V3, GND, TX and RX, and that is
the whole harness. There is nothing else to order.

**Indicative total: ~40 €** plus filament.

> **The cable is not a detail.** Plenty of USB-C cables carry power and nothing
> else — the ones bundled with phone chargers usually do. With a charge-only
> cable the board lights up, the screen works, and no computer ever sees a serial
> port: the web installer finds nothing to install to and `scripts/flash.sh`
> reports no device. It reads exactly like a dead board. If a cable you know
> transfers files works, use that one.

## What is deliberately not on this list

**No separate display, no microcontroller board, no touch controller.** The
Waveshare board is all three. It costs more than a bare ESP32-S3 and removes the
entire class of display wiring problems, which on a product aimed at
non-technical users is the right trade.

**No level shifters.** The PN532 runs at 3V3 — the same as the ESP32-S3. Do not
power it from 5 V. See [../docs/WIRING.md](../docs/WIRING.md).

**No battery, by default.** TigerSpool sits next to a printer that is already
plugged in, so it is not required - see the two optional parts above if you
want one anyway. A cell you add is declared in **Settings › Battery**; until it
is, the box reports none.

## The tags

TigerSpool reads **TigerTag** NFC chips, which are not included:

- **TigerTag store** — <https://tigertag.io>
- Filament from partner brands ships with them already attached.

The tag protocol is open and documented:
[TigerTag-RFID-Guide](https://github.com/TigerTag-Project/TigerTag-RFID-Guide).

## Board variants — read this before ordering

**Waveshare sells several similar boards.** `ESP32-S3-Touch-LCD-2` is a 2.0"
240×320 panel. The 1.28", 1.69" and 3.5" boards in the same family have different
panel controllers and different pin assignments, and this firmware will not run
on them correctly. Check the silkscreen, not the listing title.

**PN532 clones vary.** The DIP switch mode table is silkscreened on the module
itself and the mapping is not always the same between clones. Read your own
module rather than trusting a table found online — including the one in
[../docs/WIRING.md](../docs/WIRING.md).

## Assembly

1. Wire the PN532 to the board exactly as in [../docs/WIRING.md](../docs/WIRING.md).
   **Four wires, two of them crossed.**
2. Set both DIP switches on the PN532 to `0` / OFF.
3. Flash the firmware from the browser — [../installer/](../installer/).
4. Verify the reader responds *before* closing the case: bring-up checklist in
   [../docs/WIRING.md](../docs/WIRING.md#bringing-a-new-build-up).
5. Mount the reader antenna away from the display's metal back and any ground
   plane. Read range is only 2–4 cm and both will eat it.
6. Close the case.

<!-- TODO(images): assembled build photo — docs/images/ -->

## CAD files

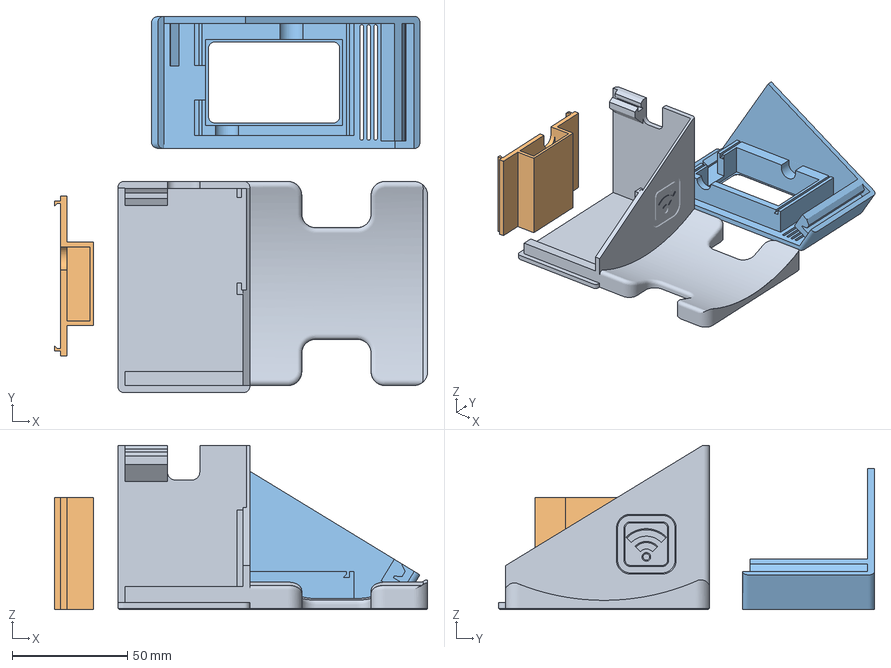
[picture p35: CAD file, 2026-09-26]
Model3D/0.Desktop/BambuStudio/tigerspool-desk-right-full.3mf
161.6 x 162.8 x 71.1 mm
Base
ecran cover
Display

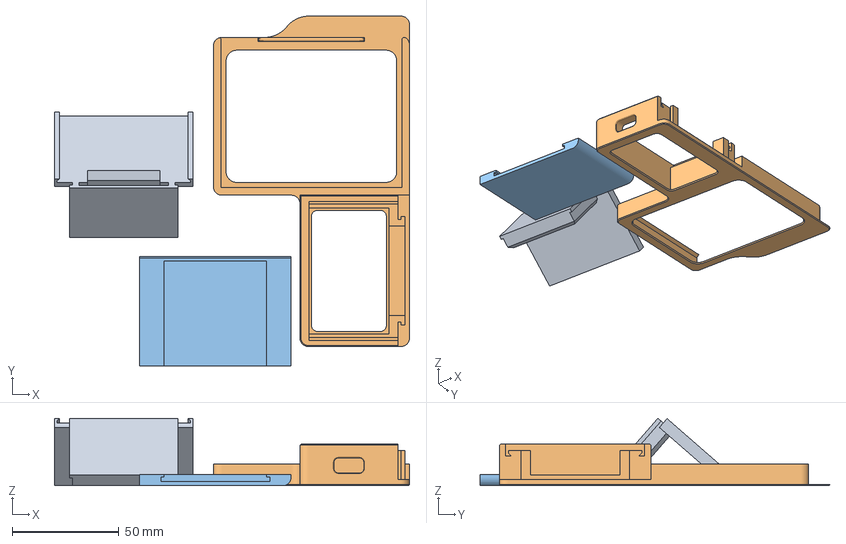
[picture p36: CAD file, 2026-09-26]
Model3D/1.BambuLab/A1-A2/BambuStudio/tigerspool-a1-a2-full.3mf
166.5 x 164.1 x 31.7 mm
RFID
Bambulab_A1-A2_Frame_V1
Bambulab_A1-A2_Cover_V1

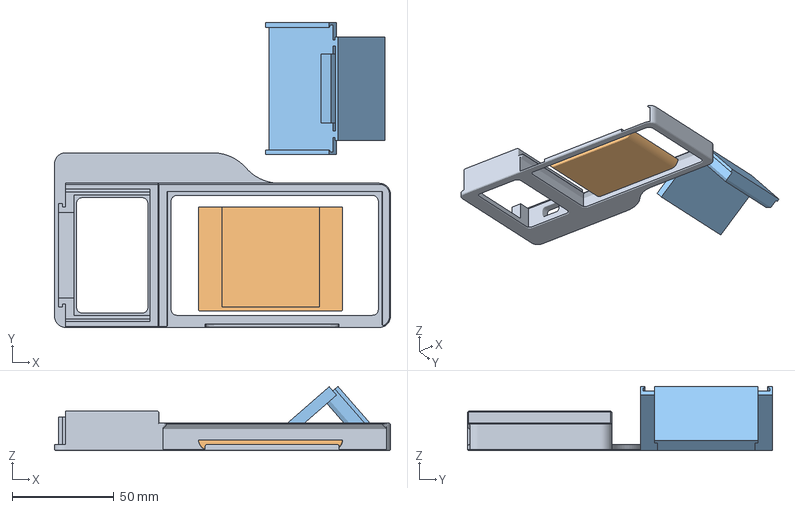
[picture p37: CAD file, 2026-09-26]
Model3D/2.Creality/K2-K2Pro/BambuStudio/tigerspool-k2-full.3mf
165.4 x 150.1 x 31.7 mm
TigerSpool_K2-K2Pro_Frame
TigerSpool_K2-K2Pro_Cover
RFID

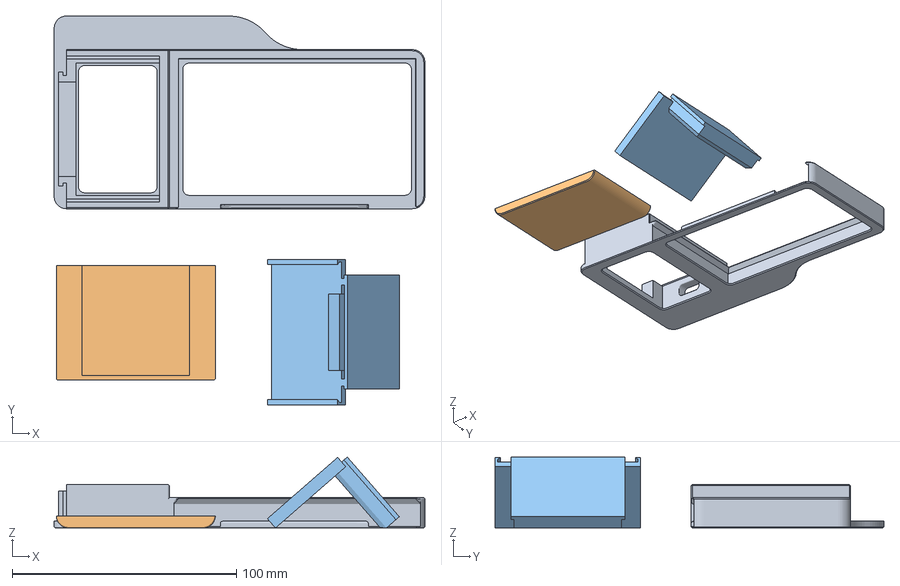
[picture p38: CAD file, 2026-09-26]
Model3D/2.Creality/K2-K2Pro/CrealityPrint/tigerspool-k2pro-full.3mf
165.4 x 173.6 x 31.7 mm
TigerSpool_K2-K2Pro_Frame
TigerSpool_K2-K2Pro_Cover
RFID

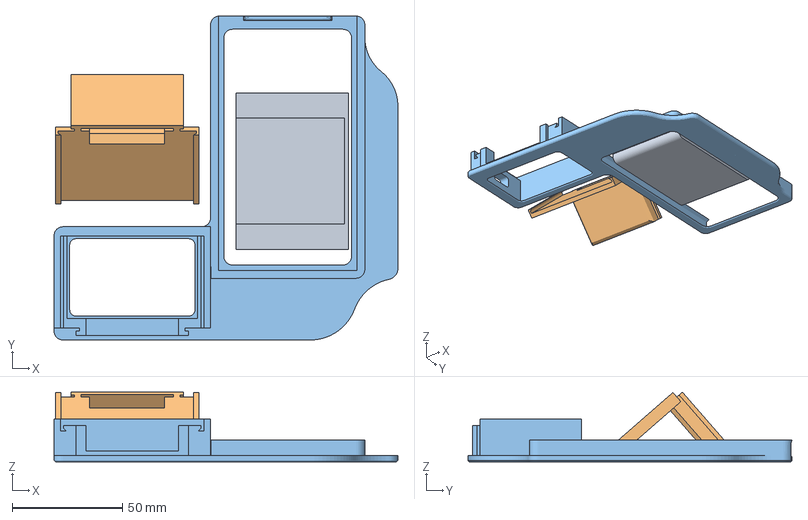
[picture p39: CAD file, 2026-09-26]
Model3D/4.FlashForge/Creator5-5Pro/BambuStudio/tigerspool-creator5-full.3mf
156.0 x 147.0 x 31.7 mm
TigerSpool_Flashforge-Creator-5-Pro_Cover
RFID
TigerSpool_Flashforge-Creator-5-Pro_Frame

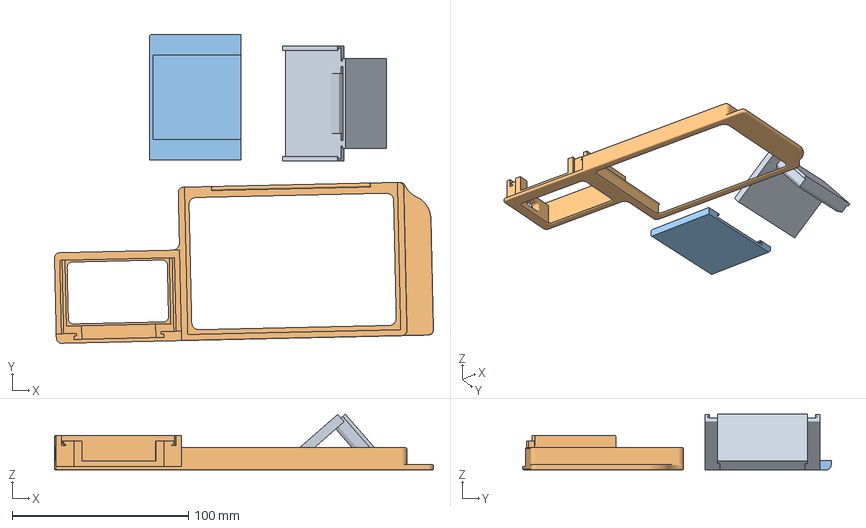
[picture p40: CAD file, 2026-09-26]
Model3D/6.Anycubic/Kobra3-Series/BambuStudio/tigerspool-kobra3-full.3mf
215.0 x 175.0 x 31.7 mm
RFID
TigerSpool_Kobra3Max_V1.2_Frame
TigerSpool_Kobra3Max_V1.2_Cover

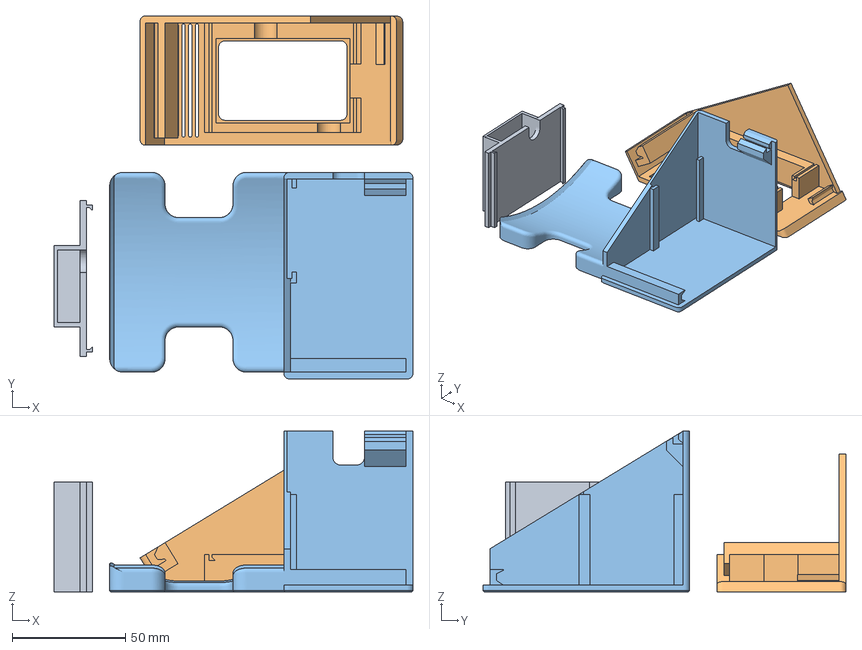
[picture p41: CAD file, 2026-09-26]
Model3D/0.Desktop/BambuStudio/tigerspool-desk-left-full.3mf
158.7 x 160.5 x 71.1 mm
ecran cover (1)
Display
Base (1) (1)

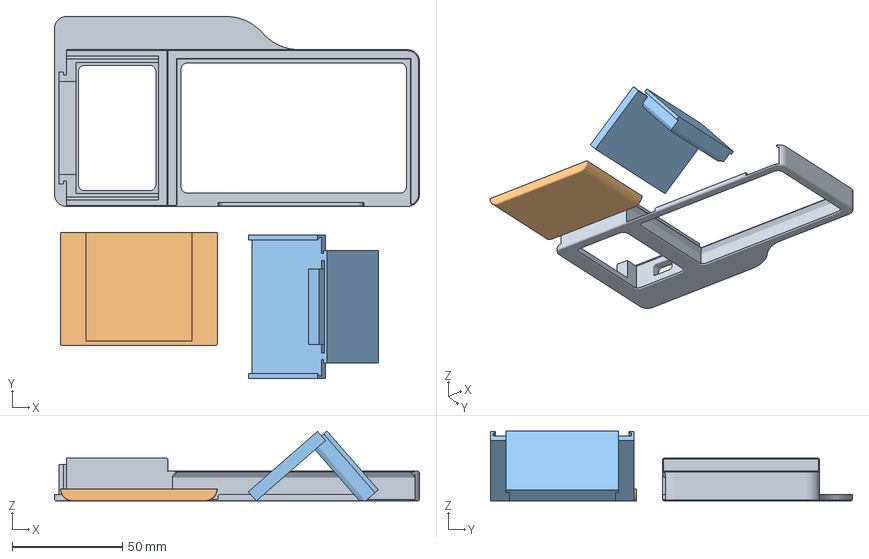
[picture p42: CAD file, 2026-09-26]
Model3D/2.Creality/K2-K2Pro/CrealityPrint/tigerspool-k2-full.3mf
165.4 x 163.9 x 31.7 mm
TigerSpool_K2-K2Pro_Frame
TigerSpool_K2-K2Pro_Cover
RFID

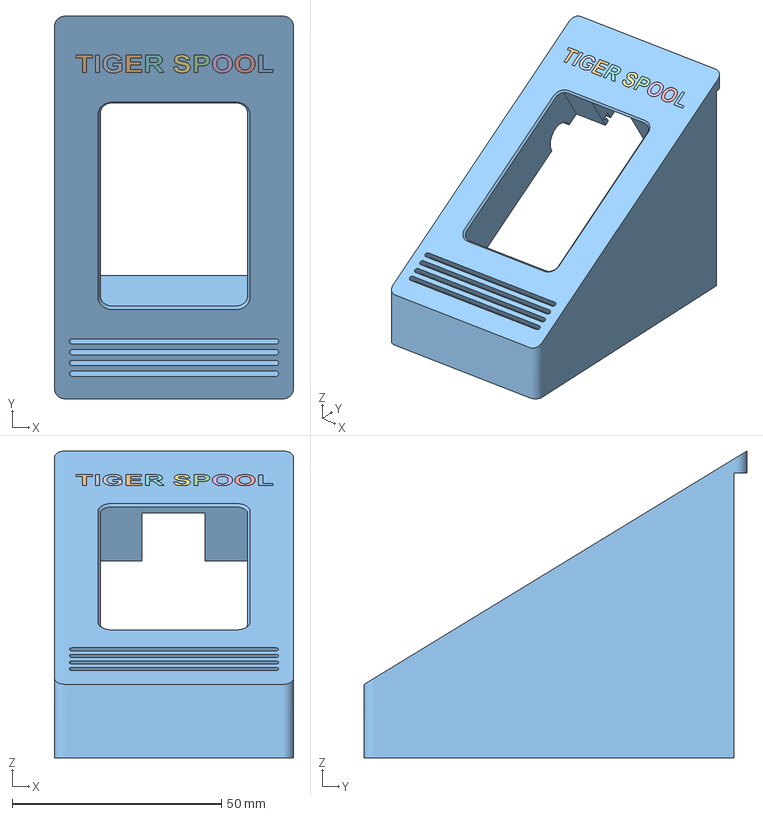
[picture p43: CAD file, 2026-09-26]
Model3D/0.Desktop/OriginalFiles/Left/tigerspool-desk-left-display.3mf
57.1 x 91.4 x 73.3 mm
Corps40
Corps41
Corps42
Corps43
Corps44
Corps45
Corps46
Corps47
Corps48
Corps49
Ecran (1)

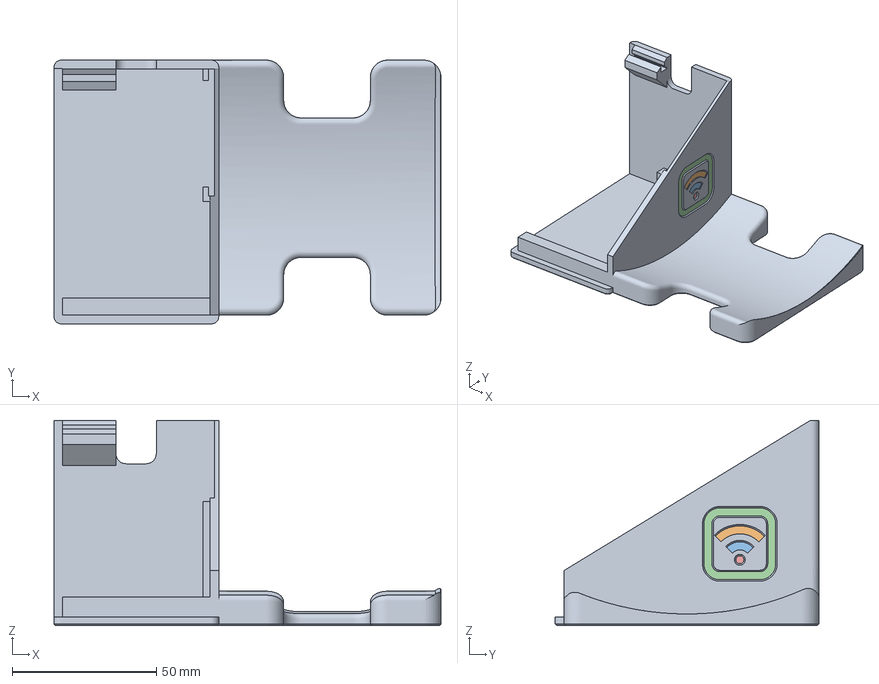
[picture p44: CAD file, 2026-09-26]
Model3D/0.Desktop/OriginalFiles/Right/tigerspool-desk-right-base.3mf
134.1 x 91.4 x 71.1 mm
Base (1)
Corps26
Corps27
Corps28
Corps29

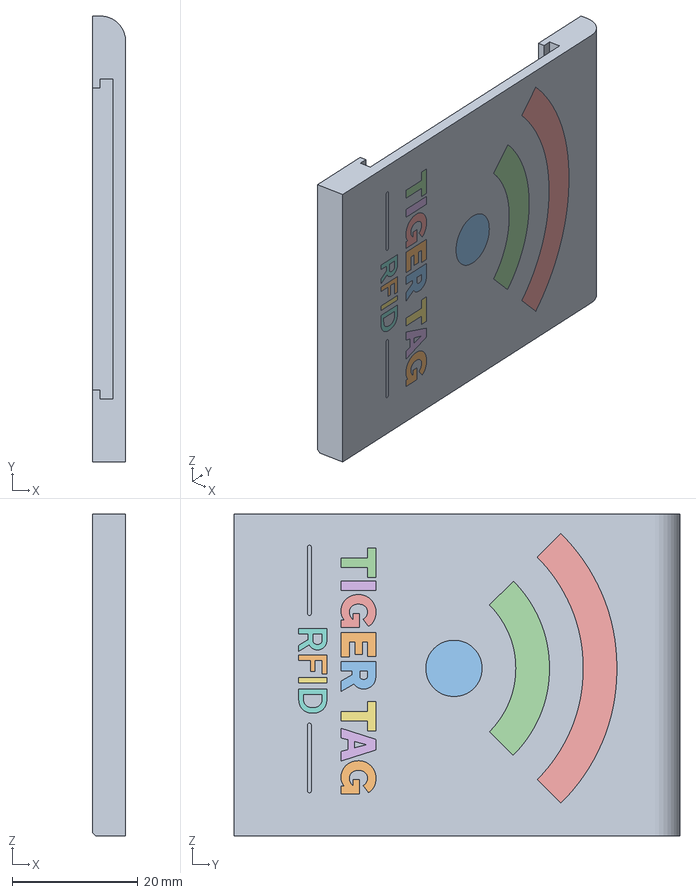
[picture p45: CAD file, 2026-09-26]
Model3D/1.BambuLab/A1-A2/OriginalFiles/tigerspool-a1-a2-cover.3mf
5.30 x 71.0 x 51.2 mm
Cover
Cover_logo (1)
Cover_logo (10)
Cover_logo (11)
Cover_logo (12)
Cover_logo (13)
Cover_logo (14)
Cover_logo (15)
Cover_logo (16)
Cover_logo (2)
Cover_logo (3)
Cover_logo (4)
Cover_logo (5)
Cover_logo (6)
Cover_logo (7)
Cover_logo (8)
Cover_logo (9)
Cover_logo

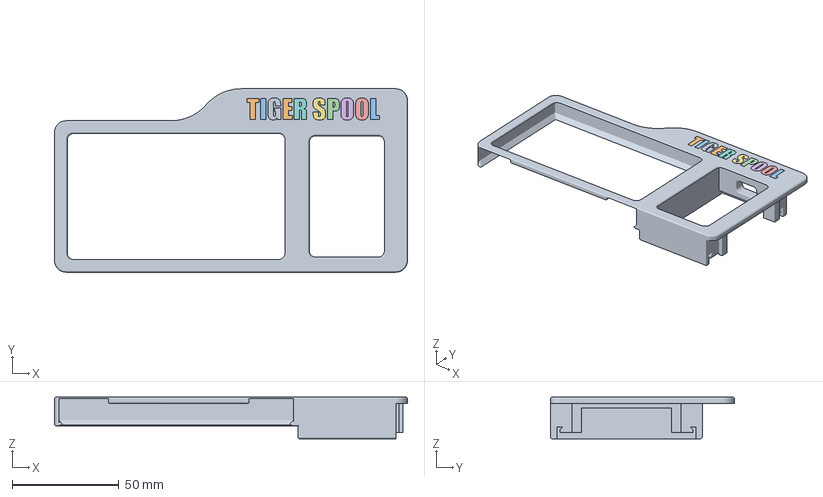
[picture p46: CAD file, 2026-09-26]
Model3D/2.Creality/K2-K2Pro/OriginalFiles/tigerspool-k2-frame.3mf
165.4 x 86.0 x 19.5 mm
Frame
Frame_logo (1)
Frame_logo (2)
Frame_logo (3)
Frame_logo (4)
Frame_logo (5)
Frame_logo (6)
Frame_logo (7)
Frame_logo (8)
Frame_logo (9)
Frame_logo

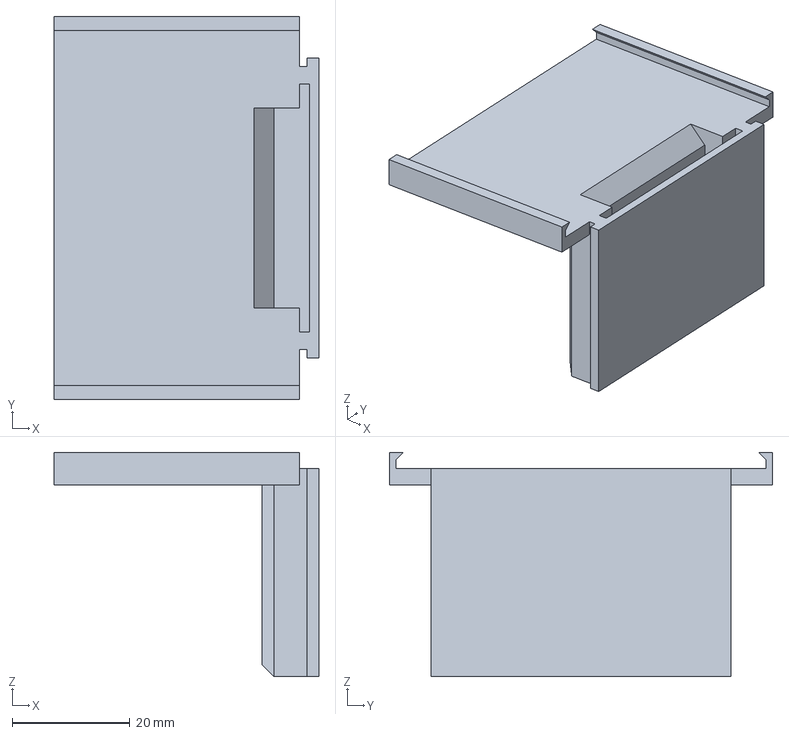
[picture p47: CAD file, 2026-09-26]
Model3D/6.Anycubic/Kobra3-Series/OriginalFiles/tigerspool-kobra3-rfid.3mf
45.0 x 65.0 x 38.0 mm

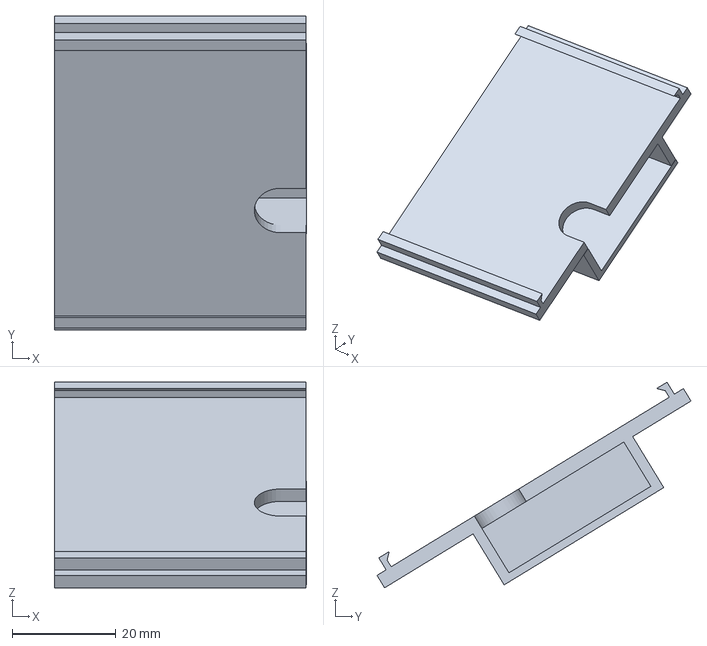
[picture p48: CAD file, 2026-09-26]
Model3D/0.Desktop/OriginalFiles/Left/tigerspool-desk-left-display-cover.3mf
48.6 x 60.5 x 39.6 mm

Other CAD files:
Model3D/0.Desktop/CrealityPrint/tigerspool-desk-right-full.3mf
Model3D/0.Desktop/CrealityPrint/tigerspool-desk-left-full.3mf
Model3D/4.FlashForge/Creator5-5Pro/OriginalFiles/tigerspool-creator5-cover.3mf
Model3D/0.Desktop/OriginalFiles/Right/tigerspool-desk-right-display.3mf
Model3D/0.Desktop/OriginalFiles/Left/tigerspool-desk-left-base.3mf
Model3D/0.Desktop/OriginalFiles/Right/tigerspool-desk-right-display-cover.3mf
Model3D/0.Desktop/Source/tigerspool-desk.f3d
Model3D/1.BambuLab/A1-A2/OriginalFiles/tigerspool-a1-a2-frame.3mf
Model3D/1.BambuLab/A1-A2/OriginalFiles/tigerspool-a1-a2-rfid.3mf
Model3D/1.BambuLab/A1-A2/Source/tigerspool-a1-a2.f3d
Model3D/2.Creality/K2-K2Pro/OriginalFiles/tigerspool-k2-cover.3mf
Model3D/2.Creality/K2-K2Pro/OriginalFiles/tigerspool-k2-rfid.3mf
Model3D/2.Creality/K2-K2Pro/Source/tigerspool-k2.f3d
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

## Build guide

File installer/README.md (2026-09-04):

# Web installer

> **Status: live** at
> <https://tigertag-project.github.io/TigerSpool-RFID/>. `index.html` is the
> page; `manifest.json`, `version.json` and the four images are generated at
> release time by `scripts/make-manifest.py` and never committed.

Flash a TigerSpool from a browser. Plug the board into a computer, open the page,
click **Install**. No PlatformIO, no Arduino IDE, no command line, no drivers to
hunt down.

Built on [ESP Web Tools](https://esphome.github.io/esp-web-tools/), which speaks
WebSerial. **Chrome and Edge on a desktop OS only** — Safari and Firefox do not
implement WebSerial, and no mobile browser does. The page has to say so plainly
rather than failing silently.

## How it will work

```
   browser                              GitHub Pages
      |                                      |
      |--- GET manifest.json --------------->|
      |<-- version + parts list              |
      |                                      |
      |--- GET the .bin files -------------->|
      |<== bootloader, partitions, app, fs ==|
      |                                      |
  [ user picks the serial port ]             |
  [ esptool.js writes over WebSerial ]       |
  [ board reboots into TigerSpool ]          |
```

Published to GitHub Pages by CI on every tagged release. **Binaries are never
committed to this repository** — they are built by the release workflow and
deployed with the page, so the installer and the OTA channel always offer the same
build. See [../docs/OTA.md](../docs/OTA.md).

## `manifest.json`

Generated by CI from the firmware's own version macro. Never hand-edited —
hand-editing is how an installer and an OTA channel drift apart.

```json
{
  "name": "TigerSpool RFID",
  "version": "1.0.0",
  "home_assistant_domain": null,
  "new_install_prompt_erase": true,
  "builds": [
    {
      "chipFamily": "ESP32-S3",
      "parts": [
        { "path": "firmware/bootloader.bin",            "offset": 0 },
        { "path": "firmware/partitions.bin",            "offset": 32768 },
        { "path": "firmware/boot_app0.bin",             "offset": 57344 },
        { "path": "firmware/tigerspool-v1.0.0.bin",     "offset": 65536 },
        { "path": "firmware/littlefs.bin",              "offset": 8454144 }
      ]
    }
  ]
}
```

> Offsets must match `firmware/partitions.csv`, and
> the filesystem offset above corresponds to the layout in
> [../docs/OTA.md](../docs/OTA.md). CI generates them from the partition table
> rather than trusting this example — **the values here are illustrative and will
> be regenerated.**

## What the page must do

**Say what is happening.** Erasing, writing, verifying, done — with progress.
A blank page during a 60-second write is where users pull the cable.

**Name the failure.** "No serial port found" needs to lead to the two real
causes: a data-capable USB cable, and a browser that is not Chrome or Edge.

**Offer the same languages as the firmware.** A user who cannot read the installer
cannot use the device.

**Erase on first install, preserve on update.** `new_install_prompt_erase` is
there so a returning user does not silently lose their Wi-Fi and their account.

## Layout

```
installer/
├── index.html      the page, with the ESP Web Tools button
├── manifest.json   generated by CI
├── locales/        translations, matching the firmware's
└── firmware/       built by CI, deployed to Pages — NEVER committed
```

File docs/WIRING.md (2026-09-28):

# Wiring

Four wires. Getting two of them the wrong way round is the single most common way
to end up with a board that boots, shows a screen, and never reads a tag.

Everything on this page was verified on a bench prototype against real hardware.
Where something is *not* verified it says so.

---

## Bill of connections

**Board:** Waveshare ESP32-S3-Touch-LCD-2 — ESP32-S3**R8**, 16 MB flash, 8 MB
octal PSRAM, 2.0" 240×320 IPS with a CST816S capacitive touch panel.

**Reader:** PN532 module (the common red V3 breakout), in **HSU** mode.

### Wiring Diagram

> [!NOTE]
> Four wires. They come with the PN532 module, so there is nothing to buy.

<p align="center">
  <a href="https://app.cirkitdesigner.com/project/5b546f4e-70b8-4735-afff-be6bd36bc10c">
    Wiring diagram: PN532 to ESP32-S3-Touch-LCD-2 — VCC to 3V3, GND to GND, TXD to GPIO44, RXD to GPIO43
  </a>
</p>
<p align="center">
  <sub><a href="https://app.cirkitdesigner.com/project/5b546f4e-70b8-4735-afff-be6bd36bc10c">Interactive schematic in Cirkit Designer</a></sub>
</p>

| PN532 pin | ESP32-S3 | Direction | Notes |
|---|---|---|---|
| `VCC` | **3V3** | — | **Not 5 V.** |
| `GND` | `GND` | — | Common ground. |
| `TXD` | **GPIO44** | PN532 → ESP32 RX | Crossed. |
| `RXD` | **GPIO43** | ESP32 TX → PN532 | Crossed. |
| `RSTO` | — | — | **Not connected.** The firmware defines no reset pin and never drives one; `config.h` declares the UART and nothing else. Leave it unwired. |
| `IRQ` | — | — | Not used. |

**Module DIP switches: both to `0` / OFF.** That selects HSU on the usual red V3
boards (`0 0` = HSU, `1 0` = I²C, `0 1` = SPI). Clones vary — read the table
silkscreened on your own module.

**Link settings:** UART1, 115200 baud, 8N1.

### The crossed-wires rule

`TXD` on the reader goes to the ESP32's **RX**, and `RXD` goes to the ESP32's
**TX**. Transmit talks to receive. If `getFirmwareVersion()` returns 0 at boot,
swap these two wires before you change anything else — it is the cause far more
often than not.

---

## ⚠️ Do not use GPIO6 and GPIO7

On this board GPIO6/7 are an **I²C bus** (camera header) and carry **pull-up
resistors**. The QMI8658 accelerometer is *not* there — a scan of this board
answers on the touch controller's bus, SDA 48 and SCL 47, at `0x6B`, and finds
nothing at all on GPIO6/7. The warning below is unchanged either way: the
pull-ups are what corrupt a UART, and an empty bus still has them.

Wiring the PN532's UART there produces a link that looks alive and is quietly
corrupt: random UIDs, `READ` commands that fail or return
garbage, tags that read once and never again.

GPIO6/7 appear in some early notes for this project and in the pin table of the
prototype's first-draft README. **That draft predates any hardware testing and is
wrong.** The bench-verified pins are 43 and 44.

### Why 43/44 are free

The ESP32-S3R8 on this board has fewer usable pins than the datasheet count
suggests:

| GPIO | Why it's unavailable |
|---|---|
| 0 | Strapping / BOOT button |
| 19, 20 | Native USB D−/D+ |
| 26–32 | SPI flash |
| 33–37 | Octal PSRAM |
| 45, 46 | Strapping |
| 47, 48 | Touch panel I²C (see below) |
| 6, 7 | On-board I²C with pull-ups — see above |

43 and 44 are the classic `U0TXD`/`U0RXD` pins. They are free here **because the
serial console runs over native USB-CDC**, not over UART0. This is why
`platformio.ini` must keep `-DARDUINO_USB_MODE=1` and
`-DARDUINO_USB_CDC_ON_BOOT=1` — dropping those reclaims 43/44 for the console
and breaks the reader.

---

## On-board peripherals (already wired, for reference)

You do not wire these — they are on the board. They are listed because they
explain which pins are unavailable.

### Display — SPI3

| Signal | GPIO |
|---|---|
| `SCLK` | 39 |
| `MOSI` | 38 |
| `MISO` | 40 |
| `DC` | 42 |
| `CS` | 45 |
| `BL` (backlight) | 1 |

Panel orientation is **rotation 2** — portrait, rotated 180°. Anything else and
the touch coordinates stop matching what is drawn.

### Touch — CST816S on I²C0

| Signal | GPIO |
|---|---|
| `SDA` | 48 |
| `SCL` | 47 |
| Address | `0x15` |

---

## What the reader can and cannot do

These are properties of the hardware, learned the hard way. Design around them
rather than trying to engineer them away.

**Range is 2–4 cm.** That is the PN532's honest range with the module's own
antenna. Keep the antenna away from ground planes and from the display's metal
back — proximity to either kills what little range there is. The enclosure
designs in [Model3D/](../Model3D/) exist partly to hold the antenna at a sane
distance.

**The module powers down between commands.** On these modules only the *first*
command after boot answers; every later one times out on the ACK. The symptom is
distinctive and misleading: the reader reports itself ready, and then reads zero
tags forever. The fix is to send a wake-up preamble before *every* command rather
than only at startup.

**Initialisation needs retries.** The first attempt fails almost every time. Retry
every 2 seconds until the firmware version comes back non-zero — and check it a
second time *after* `SAMConfig()`, because a module that answers once and then
goes quiet is exactly the failure above.

**Read pages `0x04`–`0x0B` only.** 32 bytes covers everything TigerSpool needs
(product id, material, brand, colour, temperatures). Reading them as two 16-byte
transactions instead of eight 4-byte ones is dramatically more reliable on a
marginal HSU link. Keep a 4-byte-per-page path as a fallback: when the link is
poor, smaller frames survive better than large ones.

**Read several times per tag presentation.** A single successful read is not
evidence of a good read. Validate what came back — a written TigerTag has very
few zero bytes in those pages, so a payload full of zeros means a truncated
response, not a blank tag.

**The stock Adafruit PN532 library's UART driver is not adequate here.** It
returned `FF 00 FF 00` on this hardware. The prototype uses the Seeed/elechouse
`PN532_HSU` driver with local patches; see
[docs/MIGRATION.md](MIGRATION.md#the-vendored-pn532-library) for what those
patches are and how they will be carried over.

---

## Bringing a new build up

Check in this order. Each step rules out the failure modes above.

1. **Power.** 3V3 on the PN532's VCC. Not 5 V.
2. **DIP switches.** Both at `0` / OFF.
3. **Wires.** PN532 `TXD` → GPIO44, `RXD` → GPIO43. Crossed.
4. **Idle bytes.** With the reader powered and nothing near it, the ESP32's RX
   line should be silent. Continuous garbage means TX/RX swapped, the DIPs in the
   wrong mode, a 5 V level, or the wrong UART.
5. **Firmware version.** Ask the PN532 for its firmware version. Non-zero once,
   then non-zero *again* after `SAMConfig()`. A single non-zero followed by
   timeouts is the power-down problem.
6. **A tag.** Present a TigerTag; the UID and 32 bytes of page data should come
   back. If the UID changes every read, you are on GPIO6/7.

<!-- TODO(images): wiring photo — docs/images/wiring-hsu.jpg -->

---

## Not yet verified

Listed here rather than left implied. These need bench work before they belong
in the sections above.

- **Enclosure antenna placement.** The 2–4 cm figure is measured with a bare
  module. Read distance through each printed shell in [Model3D/](../Model3D/) has
  not been characterised.
- **PN532 module variants.** Verified on the common red V3 breakout. Other
  form factors (e.g. the flat NFC antenna variants) are untested.
- **A shared reset line.** `RSTO` on GPIO4 helps init; whether it is sufficient
  to recover a wedged reader at runtime, without a power cycle, has not been
  tested.

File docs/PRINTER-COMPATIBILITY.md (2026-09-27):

# Printer compatibility

**"Any printer" is the ambition. This page is the truth.**

Marketing gets one line on the front page; this table gets the rest. If a printer
is not on it, TigerSpool does not support it. If it is on it at 🧪, that means
someone has to do work before it does.

> **Status of this page:** everything marked 🟢 *proven* below was proven with
> this repository's firmware, on real printers. Nothing here is claimed on the
> basis of documentation alone.

---

## The three levels

| | Level | What it means for you |
|---|---|---|
| ✅ | **Automatic** | Add the printer once in Tiger Studio. TigerSpool finds it, connects, and works. Nothing to configure on the device. |
| ⚙️ | **One setup step** | Works, but the printer needs one thing switched on or read off its own screen — usually LAN mode, sometimes an access code. Once. |
| 🧪 | **Experimental** | Not finished. May be partly implemented, may be unimplemented, may be broken by a printer firmware update. Do not buy hardware for this. |

---

## Support matrix

| Brand | Models | Level | Transport | Prototype status | What's needed |
|---|---|---|---|---|---|
| **Creality** | K2, K2 Plus | ⚙️ | WebSocket `:9999` | 🟢 proven on hardware | Nothing: the printer accepts local requests while it stays on Creality Cloud. |
| **FlashForge** | Creator 5 / 5 Pro, **AD5X** | ⚙️ | HTTP `:8898` | 🟢 proven on hardware | Serial number **and check code**, both from the printer's network info screen. Imported automatically if the printer is in your TigerTag account. |
| **Bambu Lab** | A1, A1 mini, A2L | ⚙️ | MQTT/TLS `:8883` | 🟢 proven on hardware | **LAN mode on**, plus the serial and the 8-character access code from the printer screen. Imported automatically from your account. |
| **Snapmaker** | Artisan, J1, J1s, U1 | ⚙️ | Moonraker WebSocket `:7125` | 🟢 proven on hardware | Nothing — Moonraker needs no authentication on the LAN. The printer's IP is all it takes. |
| **Bambu Lab (cloud)** | X1, P1, and any printer not on your LAN | 🧪 | MQTT/TLS to Bambu's broker, one session shared by every cloud printer on the account | 🟢 **reading** proven on hardware (A1, X1C) · writing not supported | **Read only**: slots are shown, a tag cannot be written - Bambu's cloud does not take the command. Depends on a Bambu session token that **Tiger Studio** obtains and stores in your account; the device never signs in to Bambu itself. The token expires roughly every three months and has to be renewed in Studio. |
| **Elegoo** | Centauri 2, Centauri 2 Combo, Centauri Carbon 2, Centauri Carbon 2 Combo | ⚙️ | MQTT `:1883` (plain TCP) | 🟢 **reading** proven on hardware (Centauri Carbon 2 Combo, with and without its CANVAS - every Centauri runs the same firmware) · writing not yet confirmed on a printer | Serial number and the MQTT password (an "Access Code" on the printer). Imported automatically from your account. |
| **Anycubic** | Kobra 3 V2, Kobra X, ACE units | ⚙️ | MQTT/TLS `:9883` | 🟢 **reading** proven on hardware (Kobra X) · writing not yet confirmed on a printer | **LAN mode**, and **the printer must be paired in AnycubicSlicerNext at least once** — its broker credentials exist nowhere else. Tiger Studio reads them from there into your account. |
| **Anycubic (cloud)** | any Anycubic not in LAN mode | ⚙️ | MQTT/TLS to Anycubic's cloud broker `:8883`, one session shared by every cloud Anycubic on the account | 🟢 **reading and writing** proven on hardware (Kobra X) | Add the printer to Tiger Studio in cloud mode: it writes the account's token and Anycubic's shared client certificate on the printer's document, and the device reads both from there. The device signs in as `web`, so it stays connected beside Tiger Studio and the slicer. When a new slicer sign-in revokes the token, refresh the printer in Tiger Studio. |

**How many at once** depends on which: a Bambu or an Anycubic takes far more of
the device's memory than the others, so the limit is a load budget rather than a
count - see [CONNECTION-BUDGET.md](CONNECTION-BUDGET.md).

> **Anycubic TLS — the supposed blocker does not exist.** Tiger Studio's protocol
> notes say the broker must be pinned to TLS 1.2 because it requests an optional
> client certificate that a TLS 1.3 stack aborts on. Probed directly against a
> **Kobra X (modelId 20030)** in LAN mode, that is not what happens: the broker
> completes **both** TLS 1.3 (`TLS_AES_256_GCM_SHA384`) and TLS 1.2
> (`ECDHE-RSA-AES256-GCM-SHA384`), sends **no** certificate request at all, and
> accepts every mbedTLS-friendly suite tried — including
> `ECDHE-RSA-AES128-GCM-SHA256`, the ESP32's default. Its certificate is
> self-signed, as expected.
>
> This may vary by model or firmware, so it is recorded as an observation rather
> than a rule. But on this hardware the ESP32 will handshake, and the largest
> stated risk for the Anycubic backend is not present. The device's own mbedTLS
> has since completed it too.

**Legend for implementation status:** 🟢 implemented in this firmware and
verified against a physical printer · 🟡 implemented, not fully verified ·
🔵 protocol fully documented and proven on real hardware **elsewhere**
([Tiger Studio](https://github.com/TigerTag-Project/TigerTag-Studio-Manager)), but
no firmware backend written yet · 🔴 nothing at all.

---

## Elegoo and Anycubic

Both have a firmware backend, over the LAN, and both read slots on real
printers. Unlike every other protocol in this project, **neither had to be
reverse-engineered**: both were already documented and working in
[Tiger Studio](https://github.com/TigerTag-Project/TigerTag-Studio-Manager), from
live captures of the vendors' own slicers against real printers:

- `renderer/printers/elegoo/PROTOCOL.md`
- `renderer/printers/anycubic/PROTOCOL.md`

That turned support from open-ended research into a porting job.

### Proven from this repository, on Benoit's own printers

Both protocols were re-checked live on 2026-09-08, against a Centauri Carbon 2
at 192.168.40.102 and a Kobra X at 192.168.20.200, using exactly the topics and
payloads the firmware backends send:

| | Elegoo | Anycubic |
|---|---|---|
| Connect | `CONNACK rc=0` with user `elegoo` + access code | `CONNACK rc=0` over TLS 1.2, self-signed |
| Register | `{"error":"ok"}` | n/a |
| Read | `2005` → Canvas `connected:1`, four trays with brand, type, `#RRGGBB` | `getInfo` → `state:success code:200`, box **-1** with **four** slots |
| Shape | matches the backend's parser | matches the backend's parser |

So the transports, the credentials, the topics and the payload shapes are all
correct. The device then read both printers itself (1.36.0): the Centauri
Carbon 2's four trays and the Kobra X's four slots, the same the printers report
to Tiger Studio. The credentials the device seemed to lack - the Elegoo access
code, the Anycubic `username` and `acuModelId` - were in the account all along;
the import was discarding them.

**mbedTLS on the ESP32 completes the Anycubic handshake** - TLS 1.2,
self-signed, no client certificate. That was the biggest open question in the
protocol notes.

Not yet confirmed on a printer: **writing** a slot, on either brand. The
commands are the ones Tiger Studio sends (below), but a write has not been read
back from the printer after the device sent it.

### What is already known

| | Elegoo | Anycubic |
|---|---|---|
| Transport | MQTT over **plain TCP**, port 1883 | MQTT over **TLS**, port 9883, self-signed |
| Auth | broker username `elegoo` + password, plus the serial number | `deviceId` + username + password |
| Read slots | method `2005` (with Canvas) / `1061` (single extruder) | `getInfo` on the `multiColorBox` topic |
| Write a slot | method `2003` (Canvas) / `1055` (single extruder) | `setInfo` on the same topic |
| Colour | `#RRGGBB`, uppercase | `[r, g, b]` array |
| Materials | a captured 50-entry `filament_code` table keyed by type × name | ~30 accepted names, sent verbatim |
| Discovery | UDP broadcast, port 52700 | `GET http://<ip>:18910/info`, no auth |

Elegoo is in some ways **simpler than Bambu Lab** — no TLS at all.

### The two things that will bite

**Anycubic's TLS.** Tiger Studio's notes say the broker demands TLS 1.2 and
requests an optional client certificate that a TLS 1.3 stack aborts on. The Kobra
X did neither (see the note under the matrix), and the ESP32 handshakes with it.
Another model or firmware may still behave as the notes say.

**Anycubic credentials cannot be obtained from the printer.** The `/info`
endpoint does not expose them and they cannot be derived from what it does expose
— that was established exhaustively, not assumed. They exist only in
AnycubicSlicerNext's own config file, which Tiger Studio decodes on the desktop
and writes to your TigerTag account.

For TigerSpool that is not an obstacle, it is the product working as designed:
the desktop does the part that is impossible on a 2.0" screen, and the device
imports the result. But it means **an Anycubic printer must have been paired in
AnycubicSlicerNext at least once**, and the documentation has to say so plainly
rather than letting a user discover it as a failure.

### LAN is written. Cloud is not, and it is not the same job.

An Anycubic printer is reachable **either** over the LAN **or** through Anycubic's
cloud, and the account says which. The LAN backend exists now. A cloud-mode
printer keeps no open local ports at all: there is nothing on the network to
connect to, and the only route is Anycubic's own service — signed REST requests
against a second broker, with signing secrets that live inside the closed slicer
and app binaries.

That is not a variant of the LAN backend with a flag set. It is a second client
against a different service, and the device cannot obtain its own credentials for
it any more than it can for the LAN one. The realistic shape is the Bambu cloud
pattern already in this firmware: **Tiger Studio holds the session and the
account carries a token the device presents.** Nothing in the firmware can be
built until that is decided, because it determines what the account has to store.

Bambu Lab's cloud path is that pattern, and it is built: Tiger Studio holds the
session, the account carries the token, and the device reads slots with it.

### Still useful from the community

- **Other models.** The captures come from specific printers. A protocol that
  holds across a brand's range is worth far more than one that fits one machine.
- **Testing** on other models, and a confirmed slot write on each brand.

## Slot names

A slot name is what the user reads on the box and matches against the machine in
front of them. It has to be the name the printer's own interface uses, and the
same one Tiger Studio shows — a slot called something else here is a slot the
user has to translate in their head.

These are taken from Tiger Studio's renderers, which are the reference:

| Brand | External | Units |
|---|---|---|
| **Bambu Lab** | `Ext.` | `A1`–`A4` for the first AMS, `B1`–`B4` for the second, and so on. An **AMS HT** is one heated slot and is labelled `HT1`, `HT2`… — the printer reports those units as id 128 and up, not as a fifth AMS |
| **Creality** | `Ext.` | `1A`–`1D` for the first CFS box, `2A`–`2D` for the second |
| **FlashForge** | `Ext.` | `1A`–`1D` for the material station. `T1`–`T4` are something else: the Creator 5 Pro's tool-changer nozzles, not station slots. |
| **Elegoo** | `Ext.` | `S1`–`S4` on a Combo - the CANVAS unit and its four colours. A Centauri without CANVAS has `Ext.` only. |
| **Snapmaker** | — | `E1`–`E4`, one per extruder |
| **Anycubic** | see below | `A1`–`A4`, `B1`–`B4`, … one row per ACE unit |

**There is one external slot per printer.** Not one per CFS, AMS or ACE unit —
one for the machine. It belongs to the printer, and it is drawn once. That is why
Tiger Studio puts `Ext.` on the first row and an invisible spacer in the same
column on every row after it: the grid stays aligned without inventing an
external spool that does not exist.

Both backends here follow it: the external slot is index 0, written once, before
any unit.

**The letter and the digit swap places between brands.** Bambu is
unit-then-position (`A1`), Creality is box-then-position (`1A`). They are not
typos.

**Reported slots are not loadable colours.** A Kobra X has four inputs in its
head. One feeds a splitter serving four ACE units — sixteen colours — and the
other three take one spool each, so the machine holds **nineteen** colours. Four
ACE units are sixteen slots, not twenty.

### Anycubic, and what is actually known

**The protocol does not describe the wiring, and a backend must not try to.** You
receive the list of ACE units. You do not learn which head input each one hangs
off, and you do not need to: the printer resolves a box and slot to a physical
path itself. Modelling the topology would be inventing a fact the machine never
sends.

What the hardware does, from the bench:

- A **Kobra X** has four inputs on the print head. Each takes one spool directly,
  or an ACE unit. So the same machine can be four direct colours, or sixteen
  through four ACE units, or a mix — and the report looks the same shape either
  way.
- A **Kobra S1** and **S1 Max** have a slot the machine calls **"Holder"**. That
  is the `Ext.` equivalent, one per printer, consistent with the rule above.

**What is not settled is how box `-1` should be labelled.** Tiger Studio's
renderer builds a per-slot prefix of `E` for box `-1`, giving `E1`–`E4` — four
external slots, against the one-per-printer rule. The header comment in that same
file says `[Ext.] [A1] [A2] …` instead. The two disagree inside one file, and the
Kobra X reports four slots on box `-1` while the S1's "Holder" is plainly one.

Decide it against a machine, not against the report. Everything else in this
table is settled.

Slot **names** are decoupled from slot **indices**: renaming is safe, adding a
slot changes the protocol mapping and is not.

## What "supported" does and does not mean

**It means:** TigerSpool can write a material name, a colour and nozzle/bed
temperatures into a numbered slot, and can read back what is currently in each
slot to show it on screen.

**It does not mean:**

- **Loading or unloading filament.** TigerSpool sets metadata. It does not drive
  the extruder. No supported printer exposes load/unload the way it exposes
  slot configuration.
- **Any colour you like.** FlashForge accepts only its own 24-colour palette;
  a tag's colour is snapped to the nearest one. Bambu Lab accepts exact RGB.
- **Any material name you like.** Each printer has a fixed vocabulary. Materials
  the printer does not know are mapped to the closest one it does.

> **What that looks like in practice.** A verified end-to-end assignment on a
> FlashForge AD5X: the tag said **PLA High Speed, R3D, `#DC123F`**; the printer
> ended up showing **PLA, `#F82D29`**. The colour was snapped to the palette's
> nearest entry and the "High Speed" variant was dropped, because those are the
> only values the printer accepts. Nothing failed — but the device must **say**
> the colour was adapted, or a user will read a correct result as a bug.
- **Working during a print.** Changing slot configuration mid-print is not
  supported and may be refused by the printer.

---

## Why a printer that "should work" may not

**Printer firmware updates.** Every protocol here except Snapmaker's is
reverse-engineered from a vendor's private API. Vendors change them without
notice and owe nobody compatibility. A printer that worked last month can stop.

**LAN mode.** FlashForge and Bambu Lab gate their local APIs behind a mode that
is off by default (on a Bambu Lab, Developer mode as well). This is the single most common reason a correctly
configured printer shows as offline. On a FlashForge Creator 5 or 5 Pro with
FlashForge's standard firmware, LAN mode also turns FlashForge Cloud off; the
official [FlashForge × TigerSystem firmware](https://tigertag-project.github.io/FlashForge-TigerTag-Creator5-Firmware-Lan-and-Cloud/download/creator5/)
keeps both on.

**Network segmentation.** Guest networks, VLANs and client isolation on the
access point will all prevent TigerSpool from reaching a printer that is
otherwise perfectly configured. They must be on the same network segment.

**Silent acknowledgements.** At least one printer answers "success" to commands it
did not understand. Where the protocol allows it, TigerSpool re-reads slot state
after writing to confirm the change actually landed — but confirmation is not
possible on every protocol.

---

## Adding a printer brand

The [architecture](ARCHITECTURE.md#printer-abstraction) is built so that a new
brand is one class implementing one interface, and touches nothing else. What
that class has to provide:

1. **Connect and stay connected** over whatever transport the printer speaks,
   recovering on its own when the network drops.
2. **Report slots** — how many, what they are called, and what is currently in
   each one.
3. **Accept an assignment** — translate a decoded TigerTag into the printer's own
   material vocabulary and colour constraints, and send it.
4. **Tell the truth about failure** — including detecting the case where the
   printer claims success and does nothing.

See [CONTRIBUTING.md](../CONTRIBUTING.md).

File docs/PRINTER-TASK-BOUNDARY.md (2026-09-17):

# Moving printer traffic off the interface loop

Step 1 of three: **the boundary**, written before any code moves. Steps 2 and 3
are issues; this file is what they are built against.

Nothing here changes behaviour. It is an inventory of who writes what, who reads
it, and where the line has to be drawn so that two threads never touch the same
bytes.

---

## Why

One loop does everything: talk to each printer, draw the screen, read the touch
panel, repeat. A connection to a printer that is switched off blocks inside the
TLS handshake, and while it blocks nothing is drawn and no touch is read.

Measured on the bench board, six printers imported and several of them off:

| | |
|---|---|
| Screen blind, total | 7.9 s out of every 80 |
| Typical gap | 56 ms |
| Worst gap | **1 324 ms** — a TLS handshake |

The worst gaps are not slow code; they are waiting. Buffering, batching and
frame pacing (all done in 1.55.0) shorten the gaps caused by printers that
answer. They cannot shorten a wait for a printer that does not.

---

## What the split has to protect

Two threads writing and reading the same bytes is the hardest class of fault to
diagnose: not reproducible, dependent on the exact instant the two cross, and
usually surfacing hours later as a reboot with no explanation. Today it cannot
happen, because there is one thread. Every line below exists to keep that true
once there are two.

### Who owns what, today

| Data | Written by | Read by | When |
|---|---|---|---|
| `SlotState slots_[]`, `nSlots_` | the backend, from its own report handler | `screen_slots.cpp` (`slot(i)`, `slotCount()`, `slotLabel(i)`), `main.cpp` after a send | every draw of the slot grid |
| `connected_`, `status_` | the backend | `main.cpp` (`tickLink`, the dialler), `screen_slots` via `linkState` | every pass |
| sockets (`WiFiClientSecure`, `PubSubClient`, `WebSocketsClient`, `HTTPClient`) | the backend | nobody else | — |
| `PrinterCfg printers[]` | `main.cpp` (`loadCfg`, account sync) | backends at `begin()`, every screen | sync, and every draw |
| `Link links[]`, `s_dialer` | `main.cpp` | `main.cpp`, `screen_slots` indirectly | every pass |
| `selectedPrinter`, `selSlot`, `state` | `main.cpp` | every screen | every pass |

The one that matters is the first row. **`screen_slots::show()` takes a
`PrinterBackend*` and reads live backend memory while it draws.** That is fine
with one thread and is exactly what breaks with two: a report arriving mid-draw
would rewrite a colour, a type or a slot count under the code reading it. The
count is the dangerous one - `nSlots_` changes at runtime, when a Bambu reports
its AMS topology, and a grid drawn against a count that shrinks reads past the
end of the array.

### The rule

> **A screen never reads a backend. It reads the last snapshot the backend
> published.**

A snapshot is a plain value - slot count, labels, states, connected flag -
copied out by the backend when it has finished updating itself, and handed over
whole. The interface thread reads the copy it was given, which cannot change
while it is being read. Nothing is locked while drawing, because the thing being
drawn is not the thing being written.

```
  printer task                        interface loop
  ------------                        --------------
  read the socket                     take the published snapshot (atomic swap)
  update slots_[]                     draw from it
  publish a snapshot  ----------->    the next draw sees the next snapshot
  handle queued commands  <--------   push assign / refresh / stop / foreground
```

Two directions, two mechanisms, both one-way:

- **State, task → loop.** A double buffer plus an atomic pointer swap. The
  publisher fills the spare copy and swaps; the reader takes the pointer once
  per draw. No mutex on the drawing path.
- **Commands, loop → task.** A FreeRTOS queue of small structs (`ASSIGN slot
  tag`, `REFRESH`, `STOP`, `FOREGROUND on/off`). Results come back as another
  snapshot, or as a queued event for the screens that wait for one (`Send`).

`assign()` is the only call that is synchronous today and must stop being so:
it writes to the printer and answers. It becomes a command plus a result event,
and the result screen waits for the event instead of a return value.

---

## What moves and what does not

**Moves to the printer task:** every socket, every backend `loop()`, every
connect, `assign()`, `refresh()`, and the reachability probe that already runs
on a task of its own.

**Stays on the interface loop, and must:**

- **Everything LVGL.** It is not thread-safe and the drawing buffers are shared
  with the panel's DMA. The rule already written in `CODEMAP.md` for the web
  server applies here unchanged.
- **The web server and `/screen.bmp`.** It reads the canvas sprite, which is
  written by the drawing code; it is safe only because both run in the same
  loop.
- **NVS writes.** `Preferences` is not reentrant across tasks in this codebase's
  usage; the account sync already respects this.
- **`printers[]` and the account sync.** The task reads it; only the loop
  writes it, and only between a `STOP` and a `BEGIN` for the affected printer.

---

## The hazards, named

| Hazard | Why it bites | What the design does about it |
|---|---|---|
| A report arriving mid-draw | `nSlots_` shrinks and the grid reads past the array | screens read a snapshot, never the backend |
| `PubSubClient` callbacks | they run inside `mqtt_.loop()`, so on the printer task | the callback only ever touches backend-owned memory |
| Heap | six TLS sessions plus a task stack, in internal RAM, already fragmented enough to have broken the account sync at 16 372 free bytes | the task's stack is sized once and measured with `uxTaskGetStackHighWaterMark`; the existing stand-down keeps its role |
| The watchdog | the loop feeds it once a pass; a task that blocks for a minute must not | the printer task subscribes to the watchdog itself, or is deliberately not subscribed and says so |
| Two writers of `printers[]` | account sync rewriting a printer a backend is using | a printer is stopped before its config is replaced - already true, and it must stay true |
| Cloud Bambu's shared session | one TLS session shared by several printers, currently pumped from the loop | it moves with the others, onto the same task, so it keeps one owner |

---

## Staged, so each stage can be judged

**Step 2 - the connects.** Only the dialling connect moves to the task; the
rest stays. It is the 1.3 s gaps, the highest value and the smallest surface: a
connect touches sockets and a `connected_` flag, and no screen reads a socket.
It needs no snapshot yet.

**Step 3 - the traffic.** Backend `loop()`, `assign()` and `refresh()` move,
the snapshot and the command queue appear, and `screen_slots::show()` stops
taking a `PrinterBackend*`.

### How each stage is judged

The same measurement, on the same bench, with the same six printers: the gap
between two LVGL frames, logged when it exceeds 40 ms.

| | Before 1.55.0 | 1.55.0 | Step 2 target | Step 3 target |
|---|---|---|---|---|
| Blind total | 8.9 s / 75 s | 7.9 s / 80 s | under 3 s / 80 s | under 1 s / 80 s |
| Worst gap | 1 318 ms | 1 324 ms | under 150 ms | under 60 ms |

A stage that does not move its number is a stage that did not work, whatever
the code looks like.

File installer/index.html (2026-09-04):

TigerTag (https://tigersystem.io)

# Install TigerSpool RFID

Firmware

1

2

Install TigerSpool

3

4

- 1× Amazon (https://link.amazon/B0c5hr3uf)
- 1× Amazon (https://link.amazon/B0dyEfwKa)
- 1× Amazon (https://link.amazon/B00Xg3WT4)

(https://github.com/TigerTag-Project/TigerSpool-RFID/blob/main/hardware/BOM.md)

(https://github.com/TigerTag-Project/TigerSpool-RFID/blob/main/docs/WIRING.md)

· tigersystem.io

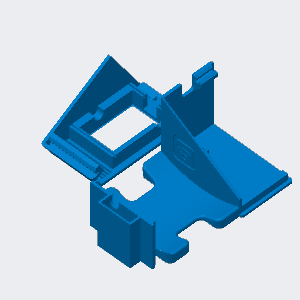
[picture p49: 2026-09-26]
Model3D/0.Desktop/Images/Left/tigerspool-desk-left-creality-print-plate.png

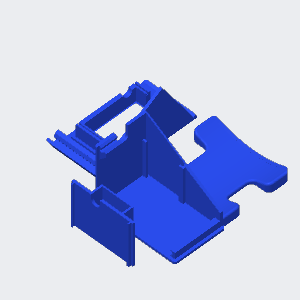
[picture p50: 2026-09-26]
Model3D/0.Desktop/Images/Right/tigerspool-desk-right-creality-print-plate.png

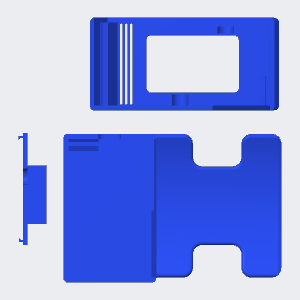
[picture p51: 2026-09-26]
Model3D/0.Desktop/Images/Right/tigerspool-desk-right-creality-print-top.png

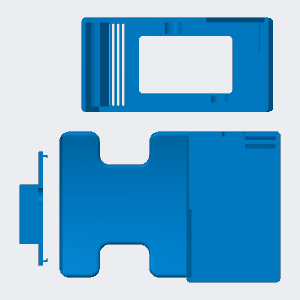
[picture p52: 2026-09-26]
Model3D/0.Desktop/Images/Left/tigerspool-desk-left-creality-print-top.png

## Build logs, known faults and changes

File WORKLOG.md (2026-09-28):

# Work log

Everything done since the last commit, in Keep a Changelog's headings, so a
release entry is synthesised from this file rather than re-derived from a diff.

**Append the moment a change is done**, not in a batch at the end. Written at the
end, this file is reconstructed from the diff — which is the exact thing it
exists to prevent.

**Describe the end state, not the journey.** An "Added X" and a later "Fixed X"
from the same cycle collapse into one entry. Anything reverted disappears
entirely: it never shipped.

At each checkpoint, synthesise this file into one line, use that as the commit
message, and reset it to this header.

---

## Unreleased

### Changed

- New wiring diagram (Cirkit Designer project 5b546f4e): board, PN532 and the
  optional 3.7 V battery on the BAT connector. `assets/wiring-diagram.jpg`
  replaced and the link updated in README.md and docs/WIRING.md; the README's
  alt text said "TX to SDA, RX to SCL", the reverse of the table - fixed.

## 2026-09-28 - A faster, steadier screen, and the certified mark at send time (released in 1.70.0)

### Changed

- `reader::read(tag, background)`: the four signature pages are read on every
  read; with `background` the ECDSA verification runs on a core-0 task
  (`tagSig`) and the tag says `SIG_PENDING` until `reader::signatureOf()` has
  the verdict. No verdict is ever cached - a chip can be rewritten under the
  same UID. Measured: read 585 ms -> 247 ms. Send path and reader mode use it;
  the NFC tester stays in the foreground. Result screen shows the certified
  mark; `S_SIG_INVALID` is now "Not certified" in grey, no warning sign.

### Fixed

- Presence heartbeat off the main loop (`ttcloud::startAsyncHeartbeat`, task
  `ttBeat`, never overlapping an account sync): measured 1.5-1.6 s of frozen
  loop every 30 s, 10.5 s on the first beat after boot.

### Added

- Bench-only code has a switch: `TIGERSPOOL_BENCH` (`src/bench.h`, 0 by
  default, `BENCH_LOG()`), on only in the new `tigerspool-bench` environment.
  `scripts/check-bench-code.py` (in verify.sh) fails on a `BENCH:` / `TEMP:` /
  `DO NOT SHIP` marker outside `#if TIGERSPOOL_BENCH`, and on the switch turned
  on for `[env:tigerspool]`. Self-tested: a marker in a bench block passes, one
  outside or in its `#else` fails, the switch in the production env fails.

## 2026-09-28 - An update no longer stalls beside a cloud Anycubic (released in 1.69.1)

### Fixed

- OTA with a cloud Anycubic selected: `standDownForTls()` now drops the
  selected printer's link too while `ota::DOWNLOADING` (and triggers on
  entering the download, which follows an already-quiet check); the Anycubic
  cloud subscription narrowed from `.../<key>/#` to `.../<key>/multiColorBox/#`.
  Bench, same device and printer: before, stalled at 442260 of 2291936 bytes and
  the network wedged; after, slot written and verified, rebooted into 1.69.0,
  the cloud session back by itself.

## 2026-09-28 - Settings > Turn off, woken by the USB cable (released in 1.69.0)

### Added

- Settings > Turn off (`E_POWER_OFF`, `showPowerOff()`, `powerOff()` in
  main.cpp): Wi-Fi off, panel asleep, backlight pin held low through deep sleep
  (a floating pad would light it); setup() releases the hold. No button wakes
  it. Without a battery, USB out and back in is a power-on. With one, the cell
  keeps it powered, so it wakes every 3 s, reads the battery pin without
  lighting anything, and boots when the pin rises 6 mV above the lowest it read
  since going off (`stayOffUnlessPlugged()`). Measured with a full cell: 1411
  mV plugged, 1397-1401 unplugged, 1425 replugged. The check is armed whether
  or not a battery is DECLARED - a fitted, undeclared cell kept a first version
  off for good. Verified end to end on the bench, declared and undeclared: off,
  cable out, cable in, back up. Three strings in nine languages; the CJK subset regenerated
  for the new characters. Verified on the bench: off, silent on the network,
  back after a reset.

## 2026-09-27 - Anycubic cloud mode, printable cases and a README that shows them (released in 1.68.0)

### Added

- Printer-mounted cases: `2.Creality/K2-K2Pro/` (Creality Print projects for
  the K2 and the K2 Pro, a Bambu Studio one, three photos, Fusion source),
  `1.BambuLab/A1-A2/` (Bambu Studio project, Fusion source),
  `4.FlashForge/Creator5-5Pro/` (Bambu Studio project) and
  `6.Anycubic/Kobra3-Series/` (every Kobra 3 model: Bambu Studio project, Fusion source). Source paths and the
  Bambu account number stripped from every project.
- `Model3D/` replaces `models/`: `0.Desktop/` (universal), then numbered
  brand directories (`1.BambuLab/` ...), then printer model; inside a model,
  `Images/`, `Source/`, `OriginalFiles/` and one directory per slicer.
  Directories may use capitals, files are lower case, nothing has a space. `TEMPLATE.md` for model READMEs, a README per brand listing its
  models.
- The desktop stand (left and right versions: Bambu Studio and Creality Print
  projects, bare parts, Fusion source, previews taken from the projects). Before publishing, object names referring to
  politicians and every `source_file` path (`C:\Users\Admin\Desktop\...`)
  were removed from the 3MFs; the `.f3d` was unpacked and scanned, clean.
- README: new "The case" section (desktop stand as the base model, printer
  integrations for the K2, Creator 5, A1/A2L and Kobra 3), MakerWorld links
  for the four published pages, device screens in `assets/screens/` and the
  two stand renders side by side above the TigerSystem hero, LAN mode and the FlashForge × TigerSystem
  firmware under printer support. `Model3D/` README, the desktop, K2 and
  Creator 5 READMEs and the Creality and FlashForge brand tables carry the
  MakerWorld links; the Creator 5 README explains the firmware;
  PRINTER-COMPATIBILITY.md mentions it under LAN mode.
- Anycubic cloud mode: `anycubic_cloud.cpp` (one MQTT/TLS session to
  `mqtt-universe.anycubic.com:8883` per account, signed in as `web` beside Tiger
  Studio's `pcf`; getInfo/setInfo published on it as on the LAN) and
  `net/legacy_tls_client.cpp` (the broker's certificate is SHA-1 signed and it
  wants mutual TLS). Token, email and client certificate read from the cloud
  printer's account document, held in RAM only: NVS silently failed to store
  the 238-character token. Measured on a Kobra X: connect, read, six writes;
  51 KB for the session (budget 50 / 4). Tiger Studio's REST orders were tried
  and dropped - a second TLS session ran the device out of memory and wedged
  its network.
- Anycubic grid kept one slot after a set: a report smaller than the known
  grid now updates it in place instead of rebuilding it (LAN and cloud).
- README printer support: every model Tiger Studio Manager offers, plus the
  Kobra 3 Max V2 and the four Elegoo Centauri, one per row with LAN and Cloud
  columns (Cloud: Bambu Lab only, read only); every README table centred.
  Elegoo slots: `S1`-`S4` on a Combo (CANVAS), `Ext.` alone without it. The
  Bambu "A2" is gone - it does not exist; the case fits the A1 and the A2L.
- `scripts/clean-3mf.py` cuts source paths to file names and lists object
  names for review; `scripts/check-models.py` (in verify.sh) enforces the
  layout, plain lower-case names and no path in a 3MF, untracked files
  included.

## 2026-09-23 - the account page, and a sign-in that no longer resets the box (released in 1.67.0)

### Added

- `/login`, signed in, is the account page: picture (`photoUrl` from
  `accounts:lookup`, once per boot on the sync task, stored in NVS only when
  there is one), name, address, a sign-out button that asks first, and a
  drawer with every printer, an on/off switch each and "Sync machines now" at
  its top. Nothing navigates: `/api/account` is read back after a sync
  (`syncCount()` moves and `changePending()` clears) and after a switch.
  Switches move at once and are put back only on a budget refusal - the web
  server is on the loop, measured 5-6 s behind a printer handshake.

### Fixed

- Email sign-in reset the device (PR #15's backtrace: `handleTtLogin` ->
  `syncNow` -> mbedTLS on the 8 KB loop stack). All four web-side syncs now
  call `ttcloud::requestSync()`; the loop stack stays at 8 KB. Measured: the
  page answers in 0.3 s, the sync runs 11.7 s on its task, taps during it
  answer in 0.45-0.57 s.

### Documentation

- CODEMAP: the `gen_db.py` rows described a generator that no longer exists;
  the battery "threshold" row contradicted the declared battery. AGENTS: the
  ASCII-only and no-Chinese rows contradicted the fonts.

## 2026-09-21 - the battery is declared, and the screen always answers (released in 1.66.0)

### Changed

- Battery detection removed entirely; `battery::declare()` / `declared()`
  replace it, stored in NVS as `bdecl`, and `present()` is the declaration.
  Benoit: "le plus simple est que l'utilisateur declare sa batterie ... pas
  besoin de gerer ca par algorythme impreccis". The measurements that killed
  the heuristics, both on the same board: a flat pack at 3.31 V rippled 6.0 mV
  (read as "no cell"), and the same board with the pack REMOVED sat at 4.05 V
  rippling 1.7 mV (read as "a cell"). The other board, empty, sits at 4.27 V
  rippling 9 mV. No threshold separates those.
  The Settings row is now always present - it is the only way in to declare -
  and carries the percentage once declared. The switch sits at the TOP of the
  battery screen: at the foot it was below the fold, and every change of state
  rebuilds that view and resets the scroll, so the control moved out from under
  the finger reaching for it. The switch also moves in its own event callback,
  before main.cpp has decided anything: the loop can be a second deep in a TLS
  handshake when the finger lands, and a control that agrees a second later is
  one somebody presses twice. The printer list has done this since it was
  written, and the rest of the view follows in the same frame through
  `lv_async_call` - deferred, because rebuilding deletes the screen the
  callback itself belongs to and LVGL walks back into that object when the
  callback returns. Six toggles in a row, uptime 53 s -> 67 s: no reset.
  Verified on the board: declare on -> 71% and the
  measured view, declare off -> present=false, percent=-1.

### Fixed

- `screen_settings`: the printers view repainted at frame rate at rest. Found
  by measuring `/screen.ver` while Benoit reported the screen "moving on its
  own": 0 frames a second on the home screen, 29-55 on this one. `updateGauge`
  rewrote both gauge labels every pass, and `setReloadBusy` re-applied the
  HIDDEN flag every pass - LVGL invalidates on both regardless of whether
  anything changed. Both are now guarded by a cache, cleared where the objects
  are rebuilt (both the settings view and the first-boot chooser). 0 frames a
  second at rest afterwards, verified on the board with the battery.
- Battery presence: the ripple test is no longer asked below 4.15 V, where the
  level already answers. Found with a real pack at 3.31 V on the second bench
  board - ripple 6.0 mV, exactly RIPPLE_NONE_MV, so the device declared no cell
  while running on one. Benoit confirmed the pack was nearly empty. After the
  fix: "3.43 V is below the charger's own level - a cell is on the connector",
  8%.
- `printer_ids` published empty, always. Two faults, one on top of the other.
  The ids were written to NVS and read back only when a sync reported a change,
  so a sync that found the same printers left them in flash with nobody reading
  them - and then the write itself turned out to fail: `putString` returned 0
  for a 361-byte value with 130 free entries, because NVS wants a blob's
  entries contiguous inside one page and this frozen 20 KB partition (500/630
  used) has no run that long. They are kept in RAM now, refreshed by every
  sync; `PrinterCfg::docId` and the `pids` key are gone. A booted device
  publishes no ids until its first sync, which is a minute or two.
  Verified on the bench: `[presence] 2 printer(s) active, 2 id(s):
  4thj8F4g0SALP27GnrOm,t1nFx693oORWqjbd3ceD`.

## 2026-09-21 - the collection goes plural (released in 1.65.0)

### Changed

- Presence writes to `tigerspools/` (plural). The Firebase side pointed out
  that every account collection is plural - scales, printers, racks - and the
  singular would have been the one exception. Free to change: 1.64.0's writes
  were all refused, so no document exists under the old path.

## 2026-09-21 - the device declares itself (released in 1.64.0)

### Added

- Presence: `ttcloud::heartbeat()` and `ttcloud::deviceId()`, plus the
  scheduler in main.cpp (`presenceTick` / `presenceWatch`). One Firestore
  `documents:commit` with an updateMask, `last_heartbeat_at` as REQUEST_TIME,
  full-then-deltas, explicit nulls, display_name read before written.
  `docs/PRESENCE.md` holds the contract.
- `PrinterCfg::docId`: the printer's document id in the account, captured at
  import and kept in NVS as ONE newline-separated key (`pids`). Twenty-four
  separate keys would have cost about fifty of the hundred and thirty NVS
  entries this device has left, in a partition that cannot grow over the air.
- pairStart now sends kind `tigerspool`, model `TigerSpool`, the real version
  and the mDNS name.
- A change of IP address forces a beat. It is what somebody uses to reach the
  box, and the moment they need it is right after the router handed out a
  different one.

**Blocked on Firebase.** Every beat comes back `403 PERMISSION_DENIED` on the
bench: the account's security rules do not name this path yet. The rule needed
is in `docs/PRESENCE.md`. Until it lands, the code is verified only as far as
"builds, runs, sends a well-formed commit and backs off when refused" - which
it does: three refusals hold the next beat for five minutes, confirmed on the
bench board (4 attempts in 80 s, then the hold).

## 2026-09-20 - the sign-in reboot, and the scan flow settled (released in 1.63.0)

### Fixed

- Email/password sign-in rebooted the ESP32; Google pairing did not. Reported
  by a user. `handleTtLogin`, `handleTtSync` and the browser-driven Google poll
  all set `restartAt`, and the reason they needed to was in main.cpp: the
  ST_MAIN and ST_PRINTER sites tested `if (asyncTake(s)) { if
  (consumeChanged()) ... }`, so a synchronous `syncNow()` from the web handler
  - which hands nothing to asyncTake - never triggered `loadCfg()`. The two
  questions are now asked separately, and the three restarts are gone with
  `W_RESTART_SUFFIX`. `forget()` still restarts; dropping a session is the one
  case where starting clean is the point.
  Verified on the bench: a POST to /tt-sync runs the full account sync (12.7 s,
  16 LAN printers) with no `rst:` in the serial log and a frame counter that
  does not restart. The email path itself is UNVERIFIED here - signing in needs
  someone's real credentials, which I do not handle.

### Changed

- `S_SIG_VALID` is "Certified" and its translations - Certifié, Zertifiziert,
  Certificado, Certificato, Certyfikowany, 已认证 - replacing "genuine" /
  "authentique". The English word was used in all nine first; Benoit: "il faut
  le mettre dans la bonne langue". It is drawn in one place, the reader
  screen's header; the NFC tester shows "OK" and is untouched.
- `S_READ_MODE` is "Scan" (Escanear / Scansione / Skanuj / Digitalizar / 扫描)
  and `S_READ_HINT` is "What is this?" - the row now names the action and asks
  the question instead of describing the hardware. The home row's hint is
  clamped to ONE line: the first French wording wrapped and pushed the row's
  own label off centre.
- `screen_read::showTag` puts the back handler on the screen, the body and the
  header, and clears LV_OBJ_FLAG_CLICKABLE on the value rows and the colour
  disc - an LVGL container is clickable from birth and swallows the click.
- `showScan` lost its `errorOrNull` argument: a failed read is logged, not
  drawn. Benoit: "ne met pas le texte rouge quand tu attends la puce".
- The scan screen keeps its Cancel button for its whole life, including the
  write. Hiding it the instant the chip was caught was tried and thrown out:
  the write is short, so the button vanished a fraction of a second before the
  screen changed anyway, and a flicker on the way out makes the device feel
  unsteady.

## 2026-09-20 - the send, straight through (released in 1.62.0)

### Changed

- ST_REVIEW is now ST_SENDING, and it has NO screen of its own. The write
  starts by itself when the tag is read and the scan screen simply stays up,
  with one change: `showScan(..., caught=true)` drops the Cancel button, since
  from that instant there is nothing left to call off. Two earlier attempts
  were thrown away first - a full screen for the send (spool, temperatures,
  spinner), then the same screen with its words changed to "Sending" - because
  the send is short enough that anything shown for it flashes past. Benoit:
  "je veux pas voir l'ecran intermediaire car c'est trop rapide". `S_SENDING`
  went with them.
  The chevron still cancels while the product endpoint is being waited for;
  once `assign()` starts it is one blocking call and runs to its end.
  `S_SEND`, `S_NO` and `S_SLOT` are gone with the buttons and the old title;
  `S_SENDING` replaces them.
- The scan screen is titled with the slot's name alone, like the receipt.
- `screen_scan::showResult` rebuilt. Benoit: un seul ecran de succes, confirmer
  l'envoi et donner l'etape suivante -> in English: one success screen, confirm
  what was sent and name the next step. Layout: tick in a green ring, "Sent to
  the printer", the spool in a bordered card, then a fixed 68 px green block
  carrying S_INSERT_IN with the slot label ALWAYS on its second line - it must
  not change height between "1" and "AMS2-4", or the screen jumps between two
  spools. The colour-adaptation pair of swatches is gone with it.
- The success screen now runs a five-second countdown drawn as a draining bar,
  and the whole screen is clickable so a tap anywhere dismisses it. `msLeft` is
  deliberately OUT of the redraw signature: the bar's width is set on the early
  return, so the screen is not rebuilt sixty times a second.
- New strings S_SENT_TO_PRINTER and S_INSERT_IN, nine languages.
- Previews `scan`, `review`, `result`, `resultlong` (AMS2-4, the layout's worst
  case) and `resultfail`: these three screens had none, so nobody could look at
  them without a printer switched on and a spool in hand.

### Added

- The drying row on the reader screen (`S_DRYING`, nine languages): "55 °C -
  4 h" from `TagInfo::dryTemp` / `dryHours`. Benoit: "le séchage c'est
  important".

### Changed

- Reader screen geometry tightened to hold a fourth value row on 320 px: disc
  68 -> 60, row gap 6 -> 4, and 8 px off the two paddings above and below the
  brand line. Verified with a real spool: PLA High Speed, drying 55 °C - 4 h,
  matching the serial decode, with "Restant 476 g" fully on screen.

## 2026-09-19 - a home screen, and reader mode (released in 1.61.0)

### Added

- A home screen that asks what you came for: two 72 px rows, **Printers** with
  how many are online under it and **Reader** with what it does. The printer
  list is one tap in and comes back with a chevron.
- **Reader mode** (`ui/screen_read.cpp`): the spool's colour as a disc, the
  material, "brand - finish - diameter", the nozzle and bed windows, what is
  left on the spool, and a green "genuine" mark in the header. The NFC tester
  keeps every raw field and stays where it was, in Settings.
- A third home row, **Write**, greyed and not clickable: no chevron, no
  pressed state, "Coming soon" under it.
- Previews `main`, `read` and `readtag` for the three new screens.

### Changed

- The account and Wi-Fi icons are on the home screen only. On the printer list
  the header carries a back chevron, the title and the gear, and 240 px does
  not hold all six.
- Settings returns to the screen the gear was pressed on, not always the home.
- The home rows start at the top rather than centred: the list grows, and a
  centred stack moves every row down each time one is added.

### Fixed

- `ui/icons.cpp`: the canvas icons (the turned Wi-Fi wave used for NFC) shared
  one static pixel buffer. Two of them on the home screen - read and write -
  meant the second drawn overwrote the first, and the read row came out grey
  instead of amber. Each one now allocates its own buffer from the LVGL heap
  (PSRAM) and frees it on LV_EVENT_DELETE; internal RAM use drops 5.8 KB.

- `scripts/flash.sh` no longer reports "no board is plugged in" when the
  PlatformIO virtualenv has lost its `esptool` module: it falls back to the
  copy that ships with the platform, and says so plainly if neither is there.

Verified on the bench board (dc:b4:d9:24:99:18) over `/api/tap` and
`/screen.bmp`: home -> printers -> back, home -> reader with a real R3D PLA
High Speed spool (215-230 / 50-60 C, 476 g, signature valid, matching the
serial decode), gear from both faces and back to each. `bash scripts/verify.sh`
passes, build included.

## 2026-09-05 - the update screen, and the header everywhere

### Changed

- The update page checks on entry. The button stays for offline and for retry.
- A 152 px progress ring, percentage inside, no header and no exit while the
  image is being written.
- The header is the ground plus a rule, not a filled bar. One style, so every
  screen changed together.
- Installed version as a settings row; the state as a glyph in a coloured ring.
- Removed the channel row and the now-dead `S_CHANNEL` key.

### Fixed

- `scripts/flash.sh` was broken without `--port`: empty array under `set -u`.

Verified on hardware: home, settings, update (checking / up to date), Wi-Fi
setup and Wi-Fi settings, driven over `/api/tap` and read back from
`/screen.bmp`.

### Changed (same cycle, folded into 1.5.0)

- `theme::WARN` added. Restart orange, factory reset red, and the Settings
  Update row orange when a version is waiting.
- One OTA check twenty seconds after boot, so the menu can show that.
- Update page: `v` prefix, smaller badge (62 px, proportionate to 240 px),
  "Wi-Fi, account and printers are kept" under an available update.
- Wording taken from the scale after reading its live view directly:
  "Installed version", "Your TigerSpool is up to date".

Answers from the TigerScale agent are in `_internal/TIGERSCALE-UI-ANSWERS.md`.
Still open from them: row icons (the scale carries the colour on a 26 px icon
and keeps the label white - we carry it on the label, having no icons), and the
font fallback chain that would restore accents.

- Settings rows now have icons. `frame::row` takes an optional LV_SYMBOL_* and
  a tint; the value's width cap drops from 108 to 84 when there is one, because
  the 28 px icon column was pushing the chevron off the row. `showMenu` takes a
  `MenuState` struct - four adjacent bools as positional arguments is a swap
  waiting to happen.

- Row icons are now drawn from LVGL primitives in `ui/icons.{h,cpp}` rather than
  taken from `LV_SYMBOL_*` where LVGL has no glyph for the thing: a person for
  the account (an envelope says "messages"), a globe for the language (a
  keyboard is not a language), a printer, a sun. The globe uses the
  TigerScale's own 22 px coordinates verbatim. About a kilobyte of code and no
  data - no font to generate, no licence to carry, nothing for a guard to
  police. The remaining four rows keep LV_SYMBOL_*, which is the right answer
  where LVGL already has the shape.
- Colour rule tightened to the scale's: an icon is plain white unless it says
  something worth seeing without reading the row. Three tinted in the healthy
  case, not six.

### Fixed

- The Settings menu showed an empty Wi-Fi network. `WiFi.SSID()` and
  `ttcloud::email()` both return String BY VALUE, and moving the call into a
  MenuState struct meant the temporaries died before the struct was read. It
  never crashed - it just looked like a network problem. Held in named locals.

## 2026-09-05 - the icons, from the scale's actual code

- `CI_USER` rebuilt verbatim: two solid discs, no outline, the shoulders clipped
  by the box. My reconstruction had used outlines and could not have matched.
- Printer and sun redrawn against the scale's silhouette rules.
- Recorded for the font work: the scale's sun is FontAwesome 6.5.2 Free Solid
  U+F185, fetched at generation time from the pinned tag, never committed. It
  rides in the generated Latin face rather than a face of its own -
  `lv_font_conv` takes several `--font` in one call. The FA font files are
  SIL OFL 1.1 and the icons CC BY 4.0; both get cited. Note that the resulting
  `Opts` line carries two `-r`, which is a trap for `check-generated.py`.
- Also from that exchange: a drawn icon costs one lv_obj per stroke in RAM for
  as long as the screen is loaded. Negligible on a settings row that exists
  once; not negligible on a list that can hold twenty. Answers in
  `_internal/TIGERSCALE-UI-ICONS-2.md`.

- The sun is now the real glyph rather than a drawing. `make-icon-font.sh`
  registered with `check-generated.py`, which had to learn that a generator is
  not always Python - it ran everything through `sys.executable` and would have
  reported "failed to run" for the wrong reason. The .ttf is cached under
  `.cache/fonts/`, keyed on the tag, so the guard re-running on every verify
  does not mean a download on every verify.
- Attribution added: Font Awesome fonts are SIL OFL 1.1, the icon artwork
  CC BY 4.0. lv_font_conv extracts outlines from the .ttf, so the OFL is what
  governs the compiled result.
- **When the Latin face is generated, fold this glyph into it and delete the
  script.** One call, several `--font`, no second face and no extra link in the
  fallback chain - and watch that the resulting `Opts` line carries two `-r`,
  which a naive generated-file check reads as one.

- Printer icon reverted to its first geometry. Widening the body and fattening
  the output tray followed the scale's "one dominant form" rule, and on the
  glass it read worse: the heavy block at the bottom took over and the printer
  stopped looking like a printer. A rule about silhouettes is not a substitute
  for looking at the thing.

## 2026-09-05 - orientation, row style, account name, a clickable live view

- `screenRotation` stored in NVS as `rot`, applied after `lvgl_port::begin()`
  so the boot logo and everything after it agree. `lvgl_port::setRotation()`
  keeps the panel in the port; main owns the value.
- `theme::LINE` is now the scale's `0x2E3646` and rows carry a 1 px border of
  it; radius 7 -> 9; row chevron 12 -> 24 px, back chevron 20 -> 24. The value
  cap drops to 74 with an icon, because the icon column and a full-size chevron
  together cost about 55 px of a 240 px row.
- `ttcloud::displayName()` - the name when there is one, the address otherwise.
  `accounts:signInWithPassword` returns `displayName`; the QR pairing path does
  not, so `fetchProfileName()` fills it from `accounts:lookup` on the next sync
  when it is missing. That is what makes it appear on a device that was already
  signed in.
- `/screen` forwards clicks to `/api/tap`, drags over 12 px as swipes.
  Coordinates come from the image's bounding rect, so it works on a phone where
  the image is scaled down.

- Wi-Fi strength on the home header, left of the gear. Four levels by colour;
  the level, not the dBm, goes into the redraw signature.

### Fixed

- Captive portal not opening on Android (reported on a Galaxy S24, iPhone on
  the same firmware was fine). `startBackgroundScan()` moved out of the last
  line of `beginAP()` and into `handlePortal()`. The AP was channel-hopping
  during the exact second Android probes for a portal. Two comments in this
  file already said scanning destabilises the AP; the call site contradicted
  them and nothing connected the two.
- **Not reproduced here** - no S24 on the bench, and the mechanism is a timing
  window that needs a real Android probe. Diagnosed from the code path and the
  iPhone/Android asymmetry. Needs the reporter to confirm.
- First boot: `startConfigAP()` draws the QR before calling `beginAP()`, and
  `beginAP()` no longer calls `doScan()`. Those two together were the several
  seconds of frozen language screen. `doScan()` stays for `/?rescan=1`.
- `beginAP()` now raises WIFI_AP rather than WIFI_AP_STA. The station interface
  was only there for the scan that no longer runs, and the file already said
  AP-only is the stable one.

## 2026-09-05 - the sign-in page

- `handleLogin()` rebuilt. Mark at the top, two fields, an eye on the password,
  the Google mark, a Tiger Studio Manager button, three community marks, and a
  legal line whose version comes from `TIGERSPOOL_FW_VERSION`.
- `scripts/make-web-asset-header.py` turns a file into a PROGMEM C string;
  `firmware/include/web_assets.h` holds the tiger icon and `/tiger-icon.svg`
  serves it. Registered with `check-generated.py`. +0.5 points of flash.
- Five new words in four languages, and W_TT_LOGIN reworded from "Connect and
  import" to "Sign in" - a button says what it does, not what follows.
- Inputs are 16 px on purpose: below that, iOS Safari zooms the page on focus.
- The last character of a typed password showing briefly is the phone's own
  behaviour, on every site. It is not controllable from a page, and the usual
  workaround (a text field with -webkit-text-security) is worse: it breaks
  password managers and puts the plaintext in the DOM.
- `pageOpen()`/`pageClose()` extracted so the sign-in and pairing pages cannot
  drift apart; the Google mark, the Studio link and the social row are PROGMEM
  blobs shared by both.
- `webcfg::webPairing()` reports a live web-initiated pairing; main draws
  `screen_setup::showPairing()` from it in a new `ST_WEB_PAIR`. Read by main,
  never pushed by webcfg - a screen driven from two places disagrees with
  itself after the next redraw.
- Two bugs found by looking at the rendered page: the pairing page emitted two
  `<!doctype html>` and two `<head>`, and the Google SVG was sized only on the
  white button, so on the orange one it filled the screen.

## 2026-09-05 - the setup AP is encrypted

- `AP_PASS` from the MAC, `WiFi.softAP(AP_SSID, AP_PASS, ...)`, QR payload
  `WIFI:T:WPA;S:...;P:...;;`, key shown under the SSID, `webcfg::apPass()`.
- `docs/WIFI-PROVISIONING.md` argued FOR the open AP. Rewritten rather than
  left to contradict the code - the argument it made was wrong on its own
  terms, because the QR format has always been able to carry a key.
- The captive-portal timing fix in 1.6.0 stands on its own, but this is the
  cause the reporter identified. Still needs the S24 to confirm.

## 2026-09-05 - the captive portal, third time

- Root cause found and TESTED, not guessed: the core `DNSServer` hardcodes
  `answerType = DNS_TYPE_A` in `replyWithIP()`, so AAAA queries get a
  type-mismatched response. `net/captive_dns.{h,cpp}` written to replace it.
- Verified with `dig` against the running device, by temporarily binding the
  resolver to port 5354 in station mode: A -> NOERROR/1 answer/60s TTL, AAAA ->
  NOERROR/0 answers. Hook reverted before commit.
- `screen_setup::showPortalReady()` + `webcfg::apClients()` drive the fallback
  QR in ST_AP. Drawn on the transition only - encoding a QR is the expensive
  part of that screen.
- The two earlier theories were both real defects and both stand: the AP no
  longer scans during the probe window (1.6.0), and it is WPA2 rather than open
  (1.8.0). Neither was the cause. Said plainly here so nobody re-litigates them
  as failed fixes.

### Fixed

- Empty network picker on first open. `startBackgroundScan()` and
  `handleApiScan()` both issued a scan immediately after raising WIFI_AP_STA;
  the scan fails if the station interface is not up yet. 80 ms settle plus one
  retry, and `if (n < 0) n = 0` no longer turns a failure into an empty result
  - the JSON carries `error` instead.

### Fixed

- Empty network picker, properly this time. The scan is not failing, it is
  succeeding with zero results because the radio is busy serving the associated
  client - so no error flag would ever have caught it. `startBackgroundScan()`
  back at the end of `beginAP()` (async), `harvestScan()` called from
  `webcfg::loop()` so the result is kept without waiting for a request, and
  `netsJson` served from there. WIFI_AP_STA is the resting mode in AP; the
  three `WiFi.mode(WIFI_AP)` drop-backs are gone.
- Proven from the boot log rather than inferred: `scan cached: 18 network(s)`
  appears before any client can associate.

## 2026-09-05 - the update notice, and a warning that was ours to remove

- `ST_UPDATE_NOTICE` + `screen_settings::showUpdateNotice()`. Entered once per
  boot, only from ST_PRINTER, only when the boot check found AVAILABLE.
  A_INSTALL_NOW calls `ota::applyAsync()` directly - they already pressed
  Install once.
- Google button: `<form method=POST>` -> `<a href>`, route no longer POST-only.
  Safari warns on any form over HTTP; that one submitted nothing.
- The warning on the e-mail form is truthful and left alone. Removing it would
  mean HTTPS, and a self-signed certificate on a device would trade a true
  warning for a scarier one.
- Update notice: `S_UPDATE_KEEPS` removed from it. Still on the update page.
- OTA check on a 6 h timer, first at 20 s. Notice gated on `notifiedVersion`
  rather than a once-per-boot flag. Verified by temporarily shortening the
  interval to 40 s and watching three checks land in the serial log at 17 s,
  55 s and 95 s; the interval was restored before commit.
- `webcfg::pairTick()` polls `ttcloud::pairPoll` from main's ST_WEB_PAIR loop.
  The meta refresh on the wait page was the only thing driving the poll, and
  iOS suspends background tabs. Measured at two minutes on a real iPhone for an
  approval that had already happened.- `frame::build(nullptr, ...)` created the title label anyway, so LVGL's
  placeholder "Text" showed in the header during the OTA download.
- `Signal` row on the Wi-Fi settings screen, from `WiFi.RSSI()`. Added to
  answer "why is the icon orange" and worth keeping: the bench unit reads
  -78 dBm while a scan sees the same SSID's beacon at -55, which is the
  difference between the beacon of the nearest access point and the live
  association - a multi-AP network, or the printed case.
- `check-ui-translated.py` now judges what is left after format specifiers word
  by word instead of whole, so `"%d dBm"` passes on dBm being a unit while
  `"Signal %d dBm"` still fails on Signal. Verified both ways.
- v1.16.0 is a dead tag: the pre-commit hook rejected the commit, the tag was
  pushed anyway, and its release workflow refused it in 11 s on the tag/macro
  mismatch. Nothing was published under it and it is left alone - the rule is
  not to re-point a pushed tag. Released as 1.17.0.

## 2026-09-05 - the legacy page, and two things it was hiding

- `routes()` registers once; `/` and `handleCaptive` decide on `apMode` at
  request time. Serving the old form to the captive portal was the symptom.
- No screen sleep in ST_LANG / ST_WIFI / ST_AP / ST_ACCOUNT / ST_WEB_PAIR.
- Deleted `page()`, `handleRoot()`, `handleSave()`, `handleReset()`,
  `handleRetry()`, `doScan()`, `load()`, `apScan`. `/reset` in particular was
  an unauthenticated GET that cleared every NVS namespace.
- The W_ table keeps its now-unused rows: the order is checked against the
  enum, and renumbering it to save a few hundred bytes is not worth the risk.
- Update page: `S_UPDATE_KEEPS` removed from it, spacer 26 -> 12, badge gap
  14 -> 8, body scrollable. The AVAILABLE layout was 20 px over 276 and the
  Install button was clipped.
- `?preview=setupdate` now renders AVAILABLE rather than IDLE. The old preview
  showed the one state that was already fine.
- Printer picker: `visible` dropped from the redraw signature, `onToggle`
  flips the switch widget in place. Rebuilding to reflect a value is the
  recurring bug in any long-lived UI - the TigerScale warned about exactly
  this - and here it cost the scroll position on every tap.

## 2026-09-05 - never rebuild a screen to show a value

- Audited every redraw signature. `showUpdate` hashed `percent`, `showWifi`
  hashed `rssi`, `showFactory` hashed `holdPercent` - all three change many
  times a second. Each keeps its widgets now and writes into them.
- Rule added to AGENTS.md's settled table, with the two costs already paid.
- `/screen`: `lvgl_port::frameCounter()` increments in the flush callback,
  `/screen.ver` serves it, the page polls that at 120 ms and fetches the 150 KB
  bitmap only on a change.
- Still on the list: `showMenu` and `showAccount` rebuild when a background
  sync changes what they show. That is a real content change rather than a
  value, so it is correct today - but the settings menu scrolls, and a sync
  landing while someone is scrolled down will move them. Worth the same
  treatment when it next matters.
- `showMenu` builds once and writes into four value labels and four icons;
  `icons::tint()` recolours a glyph or a set of drawn strokes in place. The
  update path checks `frame::screen()` before writing - the pointers do not
  survive another screen, and writing into freed LVGL objects is a crash.

## 2026-09-05 - the board knows which way up it is

- `imu.{h,cpp}`: QMI8658 at 0x6B, accelerometer only, gyroscope left off.
- Both facts measured on hardware rather than assumed. An I2C scan: GPIO6/7
  empty, touch bus carries 0x15, 0x6B, 0x7E. And the axis - Y was the obvious
  guess and reads ~50; gravity is on X, -9360 with the device upright in its
  printed holder. Threshold 4000 counts, about a quarter of a gravity, so a box
  lying flat answers "cannot tell" instead of guessing.
- First boot uses it once, when `rot` has never been stored. `autorot` is the
  new key. Rotate button on the language header sets a fixed angle and clears
  autorot; Display offers Auto / 0 / 180.
- NOT verified here: I cannot turn the device over. The reading is correct in
  its current orientation and the thresholds are measured, but somebody has to
  hold it upside down.

## 2026-09-06 - "connected permanently", and what that actually means

Answers in `_internal/TIGERSCALE-CLOUD-ANSWERS.md`. The scale separates three
things people call being connected, and the distinction settles the request:

- **A, a session that is always ready to read and write.** Verified present in
  this firmware: `refresh`/`uid` in NVS and loaded by `ttcloud::begin()`;
  `ensureToken()` is lazy - it returns immediately under 50 minutes and is
  called at the head of each authenticated operation, no timer; the periodic
  sync runs on a 16 KB task, not the UI loop. So A is done.
- **B, being told about changes.** The TigerScale does not have this AT ALL. No
  push, no Listen, no SSE, no RTDB. What looks live in Tiger Studio is a LOCAL
  WebSocket on the LAN with the scale as server - nothing to do with the
  account.
- **C, a heartbeat.** The scale PATCHes telemetry every 30 s / 5 min. We have no
  write path at all.

Done here: refresh on opening the printer picker - his recommendation 1, and
90% of the benefit for a few lines.

Not done, and it needs decisions rather than code:
- **Who owns each field.** The scale has no write conflicts because it never
  writes a field Studio owns; `displayName` is read and never written. His
  strongest advice, and it comes before the first line of any write path.
- **Who writes the signal, and when.** Any push mechanism - command queue or
  RTDB - is inert until something in the backend writes to it.
- A blocking `syncNow()` still runs from four webcfg handlers, and the web
  server is polled from the main loop, so those stall the UI for a second or
  two. Not new, and only on a page the user is already waiting on.

## 2026-09-06 - INCIDENT: firmware written to the wrong board

TigerSpool firmware was flashed onto the bench TigerScale four times.

**What happened.** Both boards were plugged into the same Mac. The TigerSpool's
port (`/dev/cu.usbmodem141401`) disappeared and a different port
(`/dev/cu.usbmodem12101`) was present, so it was assumed to be the same device
re-enumerated. It was the TigerScale. `esptool read_mac` afterwards:
`dc:b4:d9:24:99:18` is the TigerSpool, `20:6e:f1:9a:17:b4` is the TigerScale.

**What it cost beyond the TigerScale.** Every build in that window went to the
wrong board, so the TigerSpool kept running older firmware - and the "account
icon renders as a dot" bug chased for an hour did not exist. What was on screen
was the OLD sync dot, on a device that had never received the new code. A
question was sent to the sibling project about a bug that was never real.

**The fix.** `flash.sh` now reads the MAC with `esptool --no-stub read_mac`
before uploading, matches it against `.bench-mac` (gitignored), and picks that
port among all of them. No match, no write. `--any` overrides deliberately.
With no `.bench-mac` and one board it proceeds and prints the line to record;
with several it refuses and lists them.

**The lesson, and it generalises.** A serial port name is not an identity - it
is whatever the OS handed out this time. Anything destructive addressed by a
name the OS chooses needs to verify what is on the other end first.

### Added

- Account health on the home screen. `ttcloud::health()` returns 0..3 and green
  asserts that the LAST EXCHANGE succeeded: `g_lastOkMs` is stamped by every
  successful token refresh and sync, with a 12 minute TTL - two missed syncs.
- `theme::BUSY` (#2F7FFF), the fourth state colour.

## 2026-09-06 - the printer workflow, measured

Benoit's proposed workflow: sessions held open continuously to every active
printer, for live slot contents. Measured before building any of it, and the
measurement said not to.

- `backend->begin()` blocks **0 ms**. It starts a connection, it does not wait.
- On a reachable printer (Ender-3, Creality), `connected()` goes true after
  **264 ms**. There is no latency problem to solve.
- The "long loading" was a printer that is switched off. The grid appears
  instantly with the right slot labels, then waits for contents that never
  arrive, and says nothing about it. Persistent connections would not have
  changed that by one millisecond.
- And they do not fit: `MAX_PRINTERS` is 8, the Bambu backend holds a
  `WiFiClientSecure` plus a **51 200 byte** MQTT buffer, so one Bambu session is
  80-100 KB of internal RAM against 320 KB total with 37 already in LVGL's draw
  buffer. Two would be tight. Eight is impossible.

Still to do on that screen: say "unreachable" instead of waiting for ever, and
draw the last known slot contents while reconnecting.

### Added

- `showReader()` under Settings, and `ST_SET_READER` which reads continuously
  while it is open. The reader dot is gone from the slot screen.- Slot cell rebuilt to the app's three-part shape; `SlotState` gained `brand`,
  parsed from Creality's `vendor`. The other three backends leave it empty and
  the cell shows "-", which is honest rather than blank.
- `check-ui-translated.py`: "ID" added to the allow list, beside IP and MAC.

## 2026-09-06 - what was blocking the interface

Instrumented the loop to name whatever held it for more than a frame, rather
than reading the code and guessing. It printed `state 12` - ST_PRINTER, the
home screen - at 600 to 1550 ms, over and over.

Two causes, both in that state:
- `probeOne()`: `WiFiClient::connect(host, port, 900)`, one printer per pass,
  every 1200 ms. Blocking, and a printer that is off costs the full 900 ms.
- `disc::tick()`: four `connect(ip, 9999, 150)` per pass = 600 ms, repeated
  until 254 addresses are done.

Both moved to a 4 KB task on core 0. `disc` split into `sweep()` on the task
and `finish()` in the loop, because `reconcile()` rewrites `printers[].host`
and commits NVS while the screens read that array - the slow half moved, the
half that touches shared state did not.

After: 62-71 ms. The 420 ms spikes that remain are `/api/tap` pumping LVGL for
400 ms so a remote capture is stable; a real finger never goes through it.

## 2026-09-06 - the printer link is a state, not a call

Asked to confirm the connection is permanent and visible everywhere. It was
neither: `backToPrinters()` did `backend->stop(); backend = nullptr;`, so the
session lived in one view and nothing opened it when the network came up.

`linkTick()` now owns it - LINK_IDLE / TRYING / UP / GAVE_UP, five attempts,
8 s per attempt, called every loop and doing nothing once connected. A drop
after being up gets a fresh budget rather than inheriting a spent one.
`linkRetry()` re-syncs the account before trying again.

Verified from a cold boot: `[wifi] OK` then `[link] attempt 1/5` then
`[link] up`, with no churn afterwards.

**Not done:** the state shows on the slot screen (dot, or a retry button when
it has given up). The home screen still shows per-printer reachability from the
probe rather than the link state, and the settings screens show nothing. "Every
view" is therefore partly true - worth finishing once we agree where it goes,
since the header is already carrying the account and Wi-Fi at 240 px wide.
- Connection failure screen: title, QR to wiki.tigersystem.io, four causes.
  Drawn by `screen_slots` when `link == 3`, which is why that screen had to
  learn to render with no backend at all.
- **Bug I introduced in 1.28.0 and caught on hardware:** holding the session
  open meant `linkTick` saw the PREVIOUS printer's backend connected and
  reported LINK_UP. Header said K2Pro, grid showed the Ender-3's filament. The
  backends are singletons, so switching printers has to stop one before
  re-pointing it.
- Benoit, on the failure screen: leave only the title and "Scan the QR code",
  delete everything under it. He was right and I had already flagged the
  symptom myself - the fourth cause needed scrolling to reach.
- Spinner while connecting. First attempt showed a caption and no ring: the
  slot count comes from the printer MODEL, so an unreachable printer still
  reports five cells and `n == 0` was never true. The test is whether any slot
  is `known`, not how many there are.
- Second attempt still drew no ring: padding on an lv_arc insets the arc inside
  its own bounds, so 48 top + 14 bottom on a 56 px spinner left negative room.
  Margin styles are compiled out of this build; a transparent spacer object
  holds the gap instead.
- The header dot went red while the spinner said "connecting" - the screen
  arguing with itself. Hidden while the spinner is up; it returns only when
  there are slots on screen to be red about.
- Wi-Fi bars: `icons::signalBars` / `icons::setSignal`, three bars in the same
  22 px box as every other icon, written into rather than rebuilt.
- Benoit: the connect animation freezes, and the Wi-Fi one never turns at all.
  Instrumented the main loop with a 2-second worst-case report instead of
  guessing. It said `backend=5006` and `passes=1` in a five-second window -
  WebSockets' blocking connect, default WEBSOCKETS_TCP_TIMEOUT. Set to 1200 and
  re-measured: 1203 ms, passes back to ~100 per 2 s. The remaining 1.2 s is one
  stall per 8-second attempt. Removing it entirely means printer I/O on its own
  task, which is a real change and not one to make in passing - the backends
  are singletons the UI reads directly, so it needs a handoff that does not
  race on Strings.
- The Wi-Fi join screen had BOTH failure modes: rebuilt per pass (new spinner
  every frame, always at zero) and a 250 ms delay in the wait loop. Added a
  generation counter to screen_setup so a screen can tell "nothing changed"
  from "someone cleaned the screen under me" - guessing wrong either way is a
  blank panel or a spinner that never turns.
- Wi-Fi icon: arcs, not bars. Benoit's call, and the portal was already right -
  bars are the GSM symbol. Same four thresholds as `bars()` in portal_page.h.
  Bench reads -81 dBm and the panel lights the dot alone, which is what the
  phone shows for that network.
- Progress line under the spinner. It must NOT be part of the rebuild
  signature: a counter that rebuilt the screen would destroy the spinner and
  restart it at zero on every tick, which is precisely the Wi-Fi bug above.
  Written into a label held in `s_progress`, cleared on every rebuild.
- Wi-Fi arcs: mine drew correctly and the thresholds matched the portal, but
  Benoit said the image was still wrong next to the TigerScale. Asked that repo
  for its LVGL code rather than guessing a fourth time, and the answer was that
  there is no drawing at all: two stacked LV_SYMBOL_WIFI labels, one dimmed at
  50% and one lit inside a container whose HEIGHT is the level. Reproducing a
  shape could never match displaying it. Three attempts at arcs were three
  attempts at the wrong problem.
  Details worth keeping: four levels and not five, because the glyph has three
  pieces and a fifth cut lands mid-arc; clip heights measured off the panel,
  not calculated; full strength paints ONE copy because a mask cannot reach the
  apex; 50% and not iOS's 30%, which vanishes on grey cards; and LVGL does not
  re-run alignment after a size change, so the clip and the lit label must be
  re-aligned on every level change or the two copies drift apart.
  Their dBm arithmetic came across too, and I moved the portal's picker onto it
  as well - otherwise the panel and the phone would have disagreed about the
  same network, which is the problem I had just finished solving.
- Benoit asked for a scan page when a slot is tapped. It already existed -
  ST_SCAN, "present the spool", cancel - and had never been reachable: the
  colour block swallowed every press. lv_obj is CLICKABLE by default in LVGL 8.
  This is the third time that default has cost a session; icons.cpp documents
  it for drawn strokes, and it is worth remembering that it applies to any bare
  lv_obj_create placed on top of a button.
- Status dots removed from the scan/review/result screens, and the
  printerUp/readerUp parameters removed with them rather than left unused.
- **OPEN, and it matters: pressing Send takes the whole device down.** Benoit
  reported it and the board was confirmed dead - no network, no USB CDC, esptool
  could not connect. Not a sleep, not a reboot: a hang. A serial capture was
  armed to catch the backtrace and the session moved on before it was
  reproduced, so the cause is still unknown. Do NOT theorise it away - the one
  thing needed is that trace. The null slot name in the Creality status line was
  found by reading and fixed, but it invalidates a String rather than faulting,
  so it is almost certainly not this.
- The NFC-tester "freeze" was a reboot. Decoding the backtrace was what turned
  a week of guessing into ten minutes: lv_label_set_text <- showWifi, on a heap
  assert. One shared s_viewSig across screens, each XORing a constant into a
  content hash - so the tester's product-id hash could collide with the Wi-Fi
  screen's and make it write into freed widgets. A crash whose reproducibility
  depended on the contents of a chip.
- Everything else this round came from the same 2-second worst-case reporter:
  reader::read at 575 ms per frame, a 20-attempt failing read at 6.8 s,
  backend->loop at 1.2 s on every screen, webcfg::loop at 12 s while a browser
  watched, and the account sync sharing core 1 with the UI.
- Three attempts at the QR quiet zone, all wrong for different reasons, worth
  remembering: lv_qrcode rounds the requested size down to whole pixels per
  module (104 -> 98); LV_SIZE_CONTENT plus padding gave a card 6 px taller than
  wide; and lv_qrcode_update narrows the canvas WIDTH but leaves the object's
  height at the creation size. Measure the object after a layout pass, square
  it yourself, and size the card from that.
- Runtime reference tables: LittleFS was never mounted before this, and the
  partition is labelled `littlefs` while Arduino's LittleFS.begin() looks for
  one called `spiffs` - it returns false, formats nothing, and says nothing.
- Accents. The roadmap entry said "generate a Latin subset and attach it as a
  fallback face"; a fallback chain turned out to be unnecessary. One face per
  size, built from Montserrat AND FontAwesome in the same lv_font_conv call,
  replaces the built-in outright - same metrics, same symbols, wider alphabet.
  The built-ins are switched off in lv_conf.h so lv_font_montserrat_16 does not
  quietly link a second copy of every glyph.
- Two traps worth remembering. The generated sources include <lvgl/lvgl.h>
  unless LV_LVGL_H_INCLUDE_SIMPLE is defined. And a custom LV_FONT_DEFAULT must
  be declared through LV_FONT_CUSTOM_DECLARE, not with LV_FONT_DECLARE at file
  scope in lv_conf.h: that file is read before lv_font_t exists, and the error
  surfaces tens of lines deep inside LVGL's own headers.
- Cost: flash went from 30% to 45% of a 4 MB slot. Five sizes x ~350 glyphs.
- Benoit on both confirm screens: as bare as possible. The wording is his -
  "Etes-vous sur de vouloir restaurer les parametres d'usine ?" and "Redemarrer
  la TigerSpool ?".
- The restart question orphaned its question mark AGAIN at 16 px, exactly as
  the old wording did at 20. A product name in a sentence cannot be shortened,
  so the type gives way: 14 px. Worth remembering that this panel is 226 px of
  usable width and a centred question is one of the easiest things to overrun.
- The boot screen's white edges were in the PNG, not the code: columns 0 and
  239 held RGB(14,14,14) for 212 rows. Fixed in the asset and verified by
  decoding the old and new files and diffing every pixel - 424 differ, all of
  them in those two columns, dimensions unchanged. Worth doing that check
  whenever an image is rewritten programmatically; "I only meant to touch the
  edges" is not evidence.
- Elegoo and Anycubic LAN backends, ported from Tiger Studio's PROTOCOL.md for
  each brand rather than reverse-engineered. Both verified only as far as the
  bench allows: they compile, and the account import now maps the two brands to
  them (seen in the log as `-> type 5` and `-> type 6` where it used to say
  "has no backend").
- The Anycubic on this LAN has 9883 open, so the backend CAN be tested here -
  but the account holds twelve printers and MAX_PRINTERS is eight, and the
  import walks brands in a fixed order, so the two new brands are the ones that
  get dropped. Worth fixing before anyone tries to test them.
- Anycubic's three extra credentials had been anticipated in printer.h with a
  note that the sn/cc pair would not stretch. It did not. They are named fields
  now, with three more NVS keys and the same "local value wins" rule the others
  follow.
- Elegoo, live against a Centauri Carbon 2: TCP connects, the broker answers,
  and it returns rc=5 - unauthorized. Transport, port, client id and topics are
  therefore all correct and the only missing piece is the access code, which is
  empty in the account while Tiger Studio's form shows Q2CQoJ. Far more than
  "it compiles": the backend is proven up to authentication.
- Anycubic, live against a Kobra X on the same LAN: the account holds deviceId
  and password but NOT username and NOT acuModelId. Both are written by Tiger
  Studio, so this is an account-data gap rather than a firmware one - and it is
  why the TLS question the protocol notes call the biggest unknown is STILL
  unanswered. Nothing has handshaked yet.
- The missing credentials were never missing. Benoit pasted the Firestore doc
  and mqttPassword was right there; the client-side ArduinoJson filter simply
  did not name it. Two lists that had to agree, forty lines apart, with a
  CODEMAP landmine explaining that they do DIFFERENT jobs - which is true and
  is exactly what stopped anyone noticing they must still agree on names.
- Anycubic over mbedTLS: works. That was the biggest open question in the
  protocol notes and the answer is plain - connected + subscribed, TLS 1.2,
  self-signed, no client certificate.
- "Three printer connections at once" - Benoit pushed back on my claim that it
  would not fit, and he was right. Measured rather than argued: a plain MQTT
  session costs ~3 KB (~0.6 KB for the next), a setInsecure TLS session ~38 KB,
  and THREE TLS sessions all connect with 79 KB still free. My earlier "three
  TLS talkers fail" is true of the account sync, the OTA check and the table
  update, which verify against the root CA bundle - a different and much more
  expensive thing. Generalising from it was wrong.
- Multi-connection, the cheap way: one link per BRAND. The backends are
  singletons per brand, and a fleet is usually one machine per brand, so an
  array of links buys simultaneous sessions with no change to any backend. Two
  printers of one brand still cannot both connect - that needs instancing, and
  that is the day this design ends.
- The Snapmaker 403 took the library's own DEBUG_ESP_PORT trace to find. Worth
  remembering that WebSocketsClient sends `Origin: file://` and
  `Sec-WebSocket-Protocol: arduino` by default, and that Moonraker rejects the
  first. Nothing in our own logging could have shown it: the client never
  raised an event, so every layer above saw silence.
- Verified end to end on a U1: tag read, review, send, and the printer itself
  then reports E4 as R3D / PLA / High_Speed / DC123FFF.
- Bambu cloud, read-only: everything needed for the actual session is now
  known and written down here so the next step is short.
    Firestore: users/{uid}/printers/bambulab/secrets/cloud_session
    fields:    bambuUid, mqttUsername ("u_<uid>"), region ("eu"|"us"),
               accessToken, and an expiry (Bambu's tokens last ~3 months)
    broker:    mqtts://<region>.mqtt.bambulab.com:8883, insecure TLS
    auth:      username = mqttUsername, password = accessToken
    client id: must be unique per device - a shared one makes the broker kick
               the phone or the desktop off
    topics:    subscribe device/<dev>/report, publish device/<dev>/request
               with the same pushall the LAN path already sends
  The report format is IDENTICAL to LAN, so the existing Bambu parser is
  reused unchanged. What is missing is the account fetch and a cloud flag on
  the backend.
- Bambu cloud, working: `[bambu] connecting to us.mqtt.bambulab.com:8883
  (cloud)` and the X1C's slots on the panel. Credentials come from
  users/{uid}/printers/bambulab/secrets/cloud_session, read during the account
  sync. The report is identical to the LAN one, so nothing in the parser moved.
- The eviction rule that made it possible is worth remembering: one backend per
  brand means the SELECTED printer has to be able to take it from a sibling,
  or a second printer of the same brand can never connect however long you
  wait. It cost an hour of watching the wrong IP in a log.
- check-text-english.py learned that a bare hostname is not prose. It read
  "us.mqtt.bambulab.com" as Portuguese, because ".com" is a word in it.

## 2026-09-08 - one connection per printer, and two things that hid behind that (released in 1.42.0)

### Changed

- The cloud slot notice is one message, not two: "Working only with LAN Mode +
  Dev Mode" in orange, the QR, and "Scan for tutorial" under it.
- Every backend is instantiable. All six kept their host, socket, slots and
  connected flag in file statics, so exactly one printer per brand could exist;
  state now lives in the object, and `main.cpp` builds one backend per link and
  destroys it with the link. The brand-eviction rule is gone with the reason
  for it.
- The Bambu MQTT receive buffer is 50 KB for the printer on screen and 8 KB for
  the others. A background link is asked one question - connected or not - and
  that comes from the session, not the report.
- MQTT client ids carry the printer's serial (Bambu) or device id (Anycubic).

### Fixed

- A link no longer claims a connection it did not make. `tickLink` asked the
  backend `connected()` before ever dialling; with a shared backend the answer
  belonged to the sibling that had it, so a Creator 5 Pro that was not on the
  network showed a green dot and the AD5X's four spools.
- The FlashForge backend had no `stop()` at all - it inherited the empty one -
  so it stayed authenticated after losing its link.
- A sync that reached one brand out of six no longer writes itself as the whole
  account. Five requests failed with six links open and a list of thirteen
  printers became three. A brand that did not answer now contributes what was
  stored for it, in its own place.
- Two documents for one printer: the newer one wins. An A1 switched to cloud
  mode kept its stale LAN document - and the access code the printer had since
  rotated - because dedup kept whichever came first.
- Links are opened while the heap allows and closed below 55 KB free, with a
  back-off that grows to eight minutes. Measured: nine printers switched on,
  six links live, 65 KB free, four minutes without a restart.
- The QR quiet zone on the cloud notice: the card carried a `pad_top`, and
  `lv_obj_align` measures from the content area, so the code sat off-centre and
  ran into the white edge a scanner needs.

Verified on hardware throughout: A1 Home and X1C Home connected at the same
time showing their own slots, AD5X green beside a red Creator 5 Pro, and a
forced two-brand sync failure keeping all thirteen printers.

## 2026-09-08 - the update screen says what it is moving from (released in 1.42.1)

### Changed

- The update notice and the update page show "1.41.0 > 1.42.0" - the version
  being left in dim, the one being offered in the accent - instead of the
  caption "Version available" over a single number. One label with LVGL's
  recolour markup, so the two cannot wrap or drift apart.
- The update page drops its "Installed" row while an update is offered: the
  step line already carries that version.
- `S_AVAILABLE` removed; nothing draws it any more.
- `?preview=notice` shows an upgrade rather than a downgrade.

## 2026-09-09 - links that come back, and a tool that was writing nothing (released in 1.43.0)

### Added

- **Choose printers**, a setup step after the account is linked: the account's
  printers with nothing selected, a scrollbar, and Confirm pinned below the
  list. A flag in NVS means it belongs to setting the box up, and to a factory
  reset, rather than returning after every sign-in.
- A third dot state: blue while the device is dialling a printer, green
  connected, red not.
- A heap heartbeat in the log every thirty seconds - free, largest block, links
  up, Wi-Fi and RSSI - and `?preview=greys`, six card fill/border pairs plus a
  primary and grey ramp for questions a screenshot cannot answer.

### Changed

- Cards are a black interior and a grey outline. Chosen on the glass, not from
  a capture: every near-black grey candidate sits where the IPS gamma curve
  stops being linear, and one of them rendered as pale blue slabs on the panel
  while the buffer held near black.
- Scrollbars: one definition for every list, 6 px, in the secondary text grey
  instead of the outline grey it was invisible in, with a gutter beside it and
  a gap at each end.
- Titles are one line. LV_LABEL_LONG_DOT wraps before it truncates, so a long
  translation grew the label and pushed the header's rule off the screen.

### Fixed

- **A link that gave up never dialled again** until somebody tapped the
  printer. Left alone through one Wi-Fi blink, a device ended with every dot
  red and no way back. Giving up is a minute's pause now.
- **The interface froze whenever the network went bad.** PubSubClient waits 15
  seconds on a socket and an Arduino TLS handshake waits two minutes; six
  backends retry together the moment Wi-Fi drops. One link may dial at a time,
  holding the slot for the whole attempt, and the waits are bounded to 4 and 5
  seconds. Gating only the pump was worse than nothing: attempts were counted
  while the backend never got the call that dials.
- Links are priced before they are opened, one per pass, so the cost lands
  before the next decision. The survival floor is 32 KB and acts only on a
  shortage lasting three seconds - it was 55 KB and instantaneous, which closed
  working links on the dip an account sync makes.
- `scripts/flash.sh` wrote nothing, silently, whenever a second USB serial
  device was present: reading its MAC failed, and under `set -e` with
  `pipefail` that ended the script before it flashed. Three flashes in a row
  were believed to have landed and had not.

Measured on hardware: six printers connect unattended and hold, heap flat at
66 KB for six minutes, no restart, interface answering in 2 s. Separately, the
RFID reader was cleared of suspicion for the weak Wi-Fi - 38 samples with the
field active read 2.3 dB BETTER than 30 with it idle.

## 2026-09-09 - the heap had room, just not in one piece (released in 1.43.1)

### Fixed

- HTTPS failed outright with several printers connected: 66 KB free but a
  largest contiguous block of 29 KB, against the ~40 KB a TLS session needs in
  one piece. The update screen said "manifest HTTP -1" and the account refresh
  failed the same way. Background links now stand down for the duration of a
  TLS operation and come straight back; the selected printer keeps its link,
  and nothing new is opened while the handshake needs the room.

## 2026-09-10 - the NFC tester, and a Wi-Fi that came back (released in 1.44.0)

### Added

- `scripts/make-ui-font.sh` builds two more faces: Montserrat SemiBold 16 for
  titles and row labels, and JetBrains Mono 16 - twenty glyphs, 8 KB - for the
  page dump. Both fetched from their own projects, cached outside the tree,
  never committed; both cited in THIRD_PARTY_LICENSES.md.
- `?preview=icons` draws every icon beside its name, and `?preview=greys` six
  card fill/border pairs plus a primary and grey ramp.
- The NFC Tester's page dump is a screen of its own behind a HEX Code button:
  pages 0x04 to 0x17, four bytes a line, addressed by their real page numbers.
- `tt_aspect_colors()` in the generated database, from the `color_count` the
  API already carried. Three aspects are multicolour, not two.

### Changed

- The NFC Tester is a technical view in English in every language, one field
  per row, in a fixed order: a colour bar across the width, then UID, brand,
  tag type, material, message, aspects, kind, weights, diameter, temperatures,
  the stamp raw AND as a date, the three colours in hex, HueForge TD and the
  signature verdict.
- The colour bar carries one band per colour, and how many is the ASPECT's
  answer - never the colour bytes'. 00 00 00 is a real black and also what an
  unused slot holds; only the aspect tells them apart.
- Colours are shown in hex, and the primary with its alpha: page 0x08 is four
  bytes and the tester shows what is on the chip.
- Waiting for a tag is the reader's wave in a ring over "Waiting NFC...", with
  the reader's own state above it.
- Titles and row labels are SemiBold 16; buttons are 20; the printer list's
  names match. Weight is on titles and labels only - weight everywhere is
  weight nowhere.
- The reader row has its own icon: the Wi-Fi wave turned a quarter turn, drawn
  by rotating the glyph itself rather than redrawing it by hand.

### Fixed

- Wi-Fi is asked for again when it goes away. See its own commit.
- A tag's readings STAY on screen when the spool is taken away, and are
  replaced only by a different chip. Clearing on removal made the result vanish
  at the moment somebody wanted to read it - and made the screen flicker
  whenever detection dropped a poll, which it does.
- Padding on a button is not space above it: a label is centred in the content
  area, which padding shrinks from the top, so the word sat below the middle.
  Same fault put a ten pixel strip of bare ground inside the colour bar. Space
  is an object now, `gap()`.
- The Display row's sun matches the Language row's globe; a long title no
  longer pushes the header's rule off the screen.

Verified on hardware throughout, on a real R3D spool.

## 2026-09-10 - the pushall nobody needed (released in 1.45.0)

### Changed

- The Bambu backend no longer asks for a `pushall` every eight seconds. The
  printer publishes an AMS report by itself when a spool changes, and that
  report is 1.2 KB against the 5.9 KB of a full dump. Measured: two printers
  answering 40 pushalls in 150 seconds - 81 KB a minute - for trays that had
  not moved. A slot changed by hand arrived on its own 164 seconds after the
  last request we made. What is left is one pushall at connect, one every five
  minutes as a backstop, and one when a printer's screen is opened.
- The update page puts Install at the foot of the screen, and scrollbars are
  back to appearing only when the content overflows - the mode was only ever
  forced because `lv_obj_remove_style_all` had taken the theme's scrollbar
  style with it, which the explicit style now replaces.

### Fixed

- MQTT sessions stopped dropping. `setSocketTimeout(4)` - added this morning to
  stop the interface freezing - bounds every READ, not only the connect, and a
  5.9 KB report over a -80 dBm link sometimes takes longer than four seconds.
  The client was hanging up on printers that were answering perfectly, once per
  poll. With the poll gone the only large read is at connect: four minutes of
  observation, zero sessions lost, against four reconnections in 150 seconds
  before. A `session lost, state N` line stays in each MQTT backend so
  PubSubClient says why rather than leaving it to be guessed.

## 2026-09-10 - the update page, as one page (released in 1.45.1)

### Changed

- The update page keeps the version card on screen in every state, and shows
  what it is doing under it: a turning ring while it checks, a tick when there
  is nothing newer, and the download icon with `from > to` and Install when
  there is. The card used to be hidden the moment an update appeared - the card
  is a statement about the device and the step line is a projection, and a page
  that removes the first when the second arrives has nothing steady on it.
- The card's label is "Version", not "Installed version". The number beside it
  is the device's own; nothing else on the page could be meant.

## 2026-09-10 - what a printer actually costs (released in 1.45.2)

### Added

- `/api/memtest` (and `?all=1` for every printer on the account): closes every
  link, holds the account sync off, opens printers one at a time and reports
  each one's settled cost in internal RAM and PSRAM to the serial console.
  Written because every number taken in normal running was polluted - the sum
  of per-link deltas came to 193 KB against 135 KB measured on the whole.

### Changed

- `linkCost()` uses the measured prices. The MQTT buffers were being counted
  as internal RAM and they are not: the framework is built with
  CONFIG_SPIRAM_USE_MALLOC and a 4 KB threshold, so every buffer over that -
  the 50 KB Bambu one included - is in PSRAM already. What is internal is
  mbedTLS, pinned there by CONFIG_MBEDTLS_INTERNAL_MEM_ALLOC. A printer's cost
  is whether it speaks TLS: 40-48 KB if it does, 2-5 KB if it does not.
- The roadmap entry that proposed moving the MQTT buffers to PSRAM is rewritten:
  they are there. It now names the two real ways past three TLS printers -
  mbedTLS in PSRAM, or one TLS session shared by every Bambu on a cloud account.

Measured: three TLS printers fit and a fourth does not (47.9 KB free after the
third, and the largest free block had already fallen to 18 KB in one run - a
new session needs a piece that size); non-TLS printers are capped by the code at
ten, not by memory.

## 2026-09-10 - one session for the cloud, and a loop that cannot stay stuck (released in 1.46.0)

### Changed

- Every Bambu printer on a cloud account shares one TLS session
  (`bambu_cloud.cpp`): the second one costs 3.2 KB instead of 47.8 KB, six
  links leave 99 KB free instead of 60, and the largest free block holds at
  50 KB instead of falling to 18. Reports are routed strictly by the serial in
  their topic; proved on a real slot change on the X1C. LAN printers untouched.
- The TLS stand-down no longer closes cloud printers when the selected printer
  keeps the session open - that freed nothing and cost each a resubscribe and a
  full pushall at every account sync.
- Wi-Fi modem sleep is off on station connections, as it already was in the
  setup portal: pings ranged from 18 ms to a full second with it on.

### Fixed

- The main loop is under the task watchdog, 30 s. It froze once with no line
  on the console and would have stayed frozen until the power was cut; a stuck
  pass now panics with a backtrace and the device reboots.

### Not a firmware fault

- The device went unreachable from the network - pings lost at 97% - while its
  printer connections carried on. Not the shared session (disabled entirely:
  same), not modem sleep (off: same), and not this cycle's work at all: the
  published 1.45.2, flashed back for the test, did the same. The radio link is
  at -75 to -88 dBm.

## 2026-09-10 - a load budget, shown as a percentage (released in 1.47.0)

### Added

- `printer_budget.h`: a printer is switched on only if its **load slots** fit
  in a budget of 160 - one load slot is one kilobyte of internal RAM. Prices are
  the worst of five `/api/memtest` passes rounded up: first cloud Bambu 50,
  each further one 4, LAN Bambu 50 (assumed - never measured, both were off),
  Anycubic 41, Creality 6, Snapmaker 5, Elegoo 3, FlashForge 2. The selected
  printer is counted whether switched on or not, since it is linked either way.
- A Load gauge above the printer list in Settings > Printers and in the
  first-boot Choose printers step: a percentage, accent colour, orange from 85%,
  red with "Not enough room" for 2.5 s when a switch is refused. The refused
  switch does not move; switching off is never refused. Raw counts go to the
  console as `[budget] '<printer>' refused: <n> of 160 load slots`.
  `S_LOAD` and `S_NO_ROOM` in all eight languages.
- `docs/CONNECTION-BUDGET.md`: the reference for all of it - the measurements,
  why 160 and not 200 (32 KB survival floor, ~166 usable) and not 166 (a ~6 KB
  reserve for what the model does not count), per printer and per connection,
  and what the model does not see (fragmentation, the ten-link cap).

### Changed

- The budget was 150 with a 16 KB reserve; raised to 160 on Benoit's call,
  trading ten kilobytes of reserve for one more printer. Safe because the budget
  is not what prevents a crash - the 32 KB floor and the sustained low-memory
  closer in `main.cpp` are.
- Load slots are the measured worst case per printer and the margin lives once,
  in the reserve. An earlier draft claimed each price was "rounded up by a
  fifth"; three brands were in fact at or above their price, hidden by the
  first Bambu over-counting.
- Documentation brought in line with the firmware: README (brand table, a
  capacity section, known limitations - the "no Elegoo or Anycubic backend" and
  "no accents" items were false), PRINTER-COMPATIBILITY (Elegoo and Anycubic
  reading proven, Bambu cloud read only, the Anycubic TLS question answered),
  firmware/README (it said nothing builds), installer/README (the manifest
  example had a filesystem image that does not exist), THIRD_PARTY_LICENSES
  (LVGL was missing), ROADMAP (the shared cloud session is built), CODEMAP and
  CLAUDE.md.

### Verified on hardware

- Bench account, six printers on: gauge reads 68% (109 of 160). Switching on
  the P2S (LAN Bambu, 50) is accepted at 159 - it would have been refused at
  150 - and the bar goes orange at 99%. Then the P1P (a further cloud Bambu, 4)
  is refused: the switch stays off, the bar turns red with "Plus assez de
  place", and the console logs `'P1P Office' refused: 163 of 160 load slots`.
  P2S switched back off, 68% again. The P2S itself was unreachable from this
  network, so a LAN Bambu is still unmeasured.

### Not verified

- The vendored PN532 driver's files say BSD, THIRD_PARTY_LICENSES says
  Apache-2.0 and promises licence and NOTICE files that are not there. Flagged,
  not fixed here.

## 2026-09-10 - a printer is what it is, not where it sits (released in 1.47.1)

### Fixed

- The AD5X HOME never connected: the device dialled 192.168.20.131, an address
  the printer had left; the account said 192.168.40.105. Two causes. The import
  merged by POSITION with the stored host and access code winning whenever the
  brand matched, so a new address from the account never landed; and two
  account documents for the same AD5X (old address, new address) were both
  imported because duplicates were only recognised at the same address. The
  printer itself was fine - measured from the Mac: /checkCode answers Success at
  the new address, and it authenticates on the check code alone (any serial
  passes, a wrong code is refused with a misleading "SN is different").
- The same positional merge made X1C Home (Lan) dial the A1's address with the
  A1's code after the second AD5X document shifted the list - rc=5 for ever.
  That is finding 2 of the 2026-09-03 review, deferred then, happening now.
- Fix, without a storage migration: `samePrinter()` (type; serial, with
  FlashForge's optional "SN" prefix dropped; then same address or same mode)
  decides both duplicates and which stored entry an imported printer is. The
  switch and a discovered host move with the printer; `printerIdx` follows it.
  The account owns name, serial, access code and the Anycubic fields; the host
  is taken from the account whenever it differs from what the account gave last
  time (new key `p{i}a`), so a K2 address found by LAN discovery still stands
  until the account changes. A printer new to the device arrives switched off.
- `updatedAt` stored as a Firestore timestamp read as no date, so the rewritten
  AD5X document would have counted as the oldest of the two. `fsMillis()` reads
  integer, double and timestamp; date math checked against the account's own
  value (2026-09-10T21:20:06.421Z = 1789075206421).
- A link now carries `cfgSig()` of the settings it was opened with and
  reconnects when a sync changes them; before, an open link kept talking to the
  old address under the new name.
- The "probe says unreachable" log line names the address it probed.

### Verified on hardware

- Flashed onto the bench: first sync wrote the account's addresses, the AD5X
  link logged "settings changed - reconnecting", then `/checkCode` Success, four
  slots read (1A PLA #F82D29, 1B PLA #871787, 1C PLA 2981E6, 1D PLA #F82D29),
  link up. A1, X1C, Centauri Carbon 2 and Kobra X up beside it. The stale AD5X
  document had already been deleted from the account by then, so the duplicate
  merge and the timestamp reading are compiled and unit-checked, not yet seen
  against a live duplicate.
- U1-showroom was found switched off. No position moved in this sync, so the
  new code wrote no switch; it was shuffled by the old positional merge before
  the flash.

## 2026-09-11 - the home header's three icons, one height (released in 1.48.0)

### Changed

- Measured on /screen.bmp first: bust 21 px of ink, gear 21, Wi-Fi wave 14 -
  and 9 px then 20 px between them. Now all three occupy rows 12-32 (the gear
  10-33, see below), with 11 px of black between one icon's ink and the next.
- The wave moved to font_ui_24 (30 x 23 box, 22 rows of ink). Its signal-level
  clips were re-cut from the glyph bitmap in font_ui_24.c, not scaled from the
  16 px numbers: one level is the bottom 7 rows (row 16 is the empty gap above
  the dot), two levels are the bottom 14 rows but only 22 columns wide,
  because the outer arc's tips reach row 9 beside the inner arc's top. The
  label is dropped 5 px so the glyph fills its box exactly (font_ui_24 leaves 5
  empty rows under it).
- All three open Settings: the gear's button now spans the icon group, x 126
  to 240, the whole header height. The bust and the wave are not clickable, so
  a tap on either lands on it. The longest title ("Imprimantes",
  "Impressoras") ends at x 117, outside it.
- The gear moved to font_ui_24 too. At 20 it matched the others' ink height
  exactly and still read as the small one - Benoit saw it straight away. A
  gear is mostly gaps; it needs a few more pixels to weigh the same.

### Verified on hardware

- Bench, after four flashes: ink at x 134-150, 162-191, 203-224; gaps 11 and
  11; bust and wave rows 12-32, gear 10-33. Seen at signal level 1 only (the
  bench sits at -79 dBm); levels 2 and 3 are checked against the bitmap, not
  yet seen on the panel.
- Taps at x 128, 142, 176, 198, 213 and 232 (y 22) all open Settings; x 120,
  on the title, does not. One capture at x 176 was taken before the screen
  had switched and read as a miss; three repeats with a second's settle all
  opened Settings.

## 2026-09-11 - the nearest access point, not the first (released in 1.48.0)

### Fixed

- Benoit: the Wi-Fi icon is low on every TigerSpool, while the TigerScale next
  to it shows full reception. Not a measurement error - the formula is the
  scale's own - and not the antenna: the device's own scan heard the network
  at -47 dBm while it was associated at -79. It was on another access point.
  The driver's default WIFI_FAST_SCAN takes the first radio it hears with the
  right name, and the cached BSSID brings it back there on every reconnect and
  reboot. The TigerScale had found exactly this (-79 on CC:BA:BD:83:47:90
  against -35 on 10:5A:95:74:DE:50, the same two radios) and fixed it with an
  erased config plus WIFI_ALL_CHANNEL_SCAN and WIFI_CONNECT_AP_BY_SIGNAL. Ported
  as `staBegin()`, used at all three station connects; the portal's join sets
  the scan and sort without erasing anything.
- The "unreachable device, 97% pings lost" of 2026-09-10 was put down to "the
  radio link at -75 to -88 dBm, not this firmware". The link was that weak
  because of this; the comment says so now.

### Added

- `[wifi] OK` logs the signal, BSSID and channel. `/api/scan?all=1` lists every
  radio the device hears - SSID, BSSID, RSSI, channel, security - from a fresh
  scan.

### Verified on hardware

- First boot with the fix: still CC:BA:BD:83:47:90 at -72 - the one miss. Every
  boot after it, four of them: 10:5A:95:74:DE:50, ch 11, -45 to -54 dBm.
  The full scan shows why the choice matters: that network is on three radios
  here, at -46 (ch 11), -72 (ch 6) and -84 (ch 1).
- Pings once settled: 0/60 lost, 16 ms average, 99 max - against 20% lost and
  545 ms average on the far radio.
- The header's Wi-Fi icon at -45 to -50 dBm shows two arcs of three: full needs
  -40 or better, the same thresholds as the TigerScale. The level-2 clip is
  therefore now seen on the panel too, outer arc's tips unlit.

## 2026-09-11 - full signal from -60 dBm (released in 1.48.0)

### Changed

- `wifiLevelFromRssi()`: 3 from -60 dBm, 2 from -70, 1 from -80, else 0 -
  Benoit's call, after the bench at -45 dBm showed two arcs of three. It was
  the TigerScale's arithmetic, kept identical on purpose; the two products now
  differ, knowingly. The portal's `bars()` moved with it.

## 2026-09-11 - full brightness out of the box (released in 1.48.1)

### Changed

- Brightness with nothing stored is 100%, not 80% (`BRIGHTNESS_DEFAULT` in
  main.cpp) - Benoit's call: the setup screens are the first impression, and
  lowering it is one row under Display. The key `bright` is written by any
  Display change and by the rotate button on the first-boot language screen,
  so a device that has done either keeps its value; one that never did gets
  100% after updating.

## 2026-09-14 - what a Creality slot is sent, and from where (released in 1.49.0)

### Fixed

- `CrealityBackend::assign()` sent `rfid "0"` (never a Creality material id),
  the chip's temperatures or 190/230, the raw material as the name, and no
  pressure/selected/percent/editStatus/state. It now sends the TigerTag Connect
  app's frame with every value resolved by `filament::resolve()`:
  temperatures (as a pair) endpoint -> chip -> table -> 190/240; `rfid` and
  pressure endpoint -> table -> "0"/0.04; name endpoint `crealityLabel` ->
  "Generic <material>". The endpoint counts only for a TigerTag+
  (protocol 3155151767) and only for its own product id. Invalid values fall
  through: a pair with a 0 or min > max, a string null/""/"-", a pressure that
  is not a positive number or numeric string (the endpoint sends it as "").
- The endpoint (`product/get?uid=<uid as decimal>&product_id=`) is asked by
  `product_api` on a core-0 task the moment a TigerTag+ is read for a Creality,
  so the answer is normally in before Send; Send waits only while that fetch is
  inside 3 s, and a late answer is cached for the next time, never sent.
- The material table keeps `metadata.crealityID`,
  `metadata.crealityPressureAdvance`, `recommended.nozzleTempMin/Max`: in the
  downloaded file (PSRAM, beside the labels) and in the compiled header
  (`TT_MATERIAL_INFO`, emitted by gen_db.py). `tt_db::materialInfo()` answers
  from the same layer as `material()`. db_update.py needed no change - it
  already stores the API's JSON whole; gen_db.py is what compiles it.
- The immediate re-read after a write is deferred 1.5 s on Creality: the
  printer answers boxsInfo with the old slot for about a second. main.cpp's
  generic refresh() after Send lands in that window, so refresh() itself
  reschedules rather than assign() just not calling it.

### Changed

- The TLS stand-down is split: every TLS request still holds new links back,
  but the product fetch stands links DOWN only if the largest free block was
  under 48 KB when it started. Measured with a temporary loop timer: during a
  fetch the worst loop pass stayed at 115-117 ms (baseline ~100); in the three
  seconds AFTER it, 776-952 ms - the five stood-down links dialling back, the
  Anycubic's TLS connect blocking the loop - landing exactly on Send. The
  stand-down itself takes 7-10 ms and now says so in its log line.

### Added

- `/api/resolve?protocol=&product=&uid=<hex>&material=&nozmin=&nozmax=`: the
  whole resolution from query parameters, without a spool and without sending.

### Verified

- Host test (clang, ArduinoJson from .pio/libdeps, the generated header with a
  stub Arduino.h), with the real endpoint answer and injected variants: all
  eight scenarios of the brief plus nine validity cases pass. One difference
  from the brief's table: `id_material[38219]` carries
  `crealityPressureAdvance: 0.04`, so pressure resolves `0.04(db)`, not
  `0.04(default)` - same value, the source the rules give.
- Device, `/api/resolve`: plain TigerTag -> `requested:false`, no network;
  TigerTag+ -> handler answers in 40-109 ms while the fetch runs (861-1000 ms),
  then `215/230(api) 00001(api) Generic PLA(api)` from the cache; material not
  in the table -> `0(default)`, `190/240(default)`.
- Ender-3 V4 + CFS at 192.168.40.103, a real TigerTag+ spool (product
  1127944810, R3D PLA High Speed, chip 215-230): fetch 861 ms at read, Send
  resolved `rfid=00001(api) temp=215/230(api) pa=0.04(db) name="Generic
  PLA"(api)` and sent the frame field for field. Read back over the printer's
  own WebSocket from the Mac: slot 1D took type, vendor, name and colour.
  It reported `rfid "0"`, `editStatus 0`, `state 0` - 1D holds no spool, and
  every empty slot on that CFS reads back the same way - and minTemp/maxTemp
  0, which boxsInfo reports for every slot including one with rfid "00004".
  Whether a slot holding a spool keeps the rfid is not verified yet.
- Then every slot (Ext, 1A-1D, three of them holding spools), through the
  TigerSpool with the same spool: type, vendor, name, colour and pressure
  landed everywhere; `rfid` read back "0" everywhere - 1A's previous "00004"
  included, so the printer does write that field and is refusing ours.
- Why, found by sending variants straight from the Mac to slot 1C and reading
  back: the printer keeps an rfid ONLY when vendor, type and name match its own
  entry for that id.
  `00001` + PLA + R3D + "Generic PLA"            -> rfid "0"
  `00001` + PLA + Generic + "Generic PLA"        -> rfid "00001" kept
  `00001` + PLA + Generic + "R3D PLA High Speed" -> rfid "0"
  `01001` + PLA + R3D + "Hyper PLA"              -> rfid "0"
  `01001` + PLA + Creality + "Hyper PLA"         -> rfid "01001" kept
  Pressure advance is stored either way (0.055 and 0.066 read back as sent).
  minTemp/maxTemp read back 0/0 in every case, kept rfid or not - boxsInfo does
  not report them, so whether the printer stores them cannot be seen from here.
- So the brief's frame - vendor = the tag's brand, type = the material label -
  can never keep a Creality id for a spool that is not Generic. Open, for
  Benoit: send vendor "Generic" / type = material family / name =
  crealityLabel when a Creality id is resolved (the printer then shows
  "Generic PLA", not R3D), or keep the brand and label and lose the id.
- Every slot was put back to its values from before the tests and read back
  identical, 1A's "00004" included.
- Where a Creality printer keeps temperatures, looked for rather than assumed:
  - boxsInfo reports minTemp/maxTemp 0 for every slot an application wrote,
    rfid kept or not. Tiger Studio's RETRO.md has the one non-zero case: a
    slot the CFS read from a Creality spool's own tag, 01001, 190/240.
  - `reqMaterials` on this Ender-3 V4 returns its material library: 18
    profiles, each an id with a brand, a name, a type and a temperature window
    (00001 Generic / Generic PLA / PLA 190-240; 01001 Creality / Hyper PLA /
    PLA 190-240; 00004 Generic ABS 240-280; ...). That library is what the
    vendor+type+name check above is checked against.
  - Klipper's own state over Moonraker (`box`, `filament_rack`) holds, per
    slot, `material_type` (the id, "000004"), `color_value` and `vender` - and
    no temperature field at all.
  So on this printer a slot's temperatures exist only as the library profile
  its id points to. The minTemp/maxTemp in modifyMaterial are sent (the log
  shows 215/230) and nothing on the printer that can be read back holds them.
  Benoit's call for now: keep the tag's brand and label, so the id is dropped
  and no profile applies. Whether the printer's own screen shows the sent
  window is the one check left, and it needs someone at the printer.

## 2026-09-14 - slot screen text in white (released in 1.49.0)

### Changed

- screen_slots.cpp: the slot name above each colour block and the brand under
  it are theme::TEXT, not TEXT_DIM - Benoit's request; at 12 px on black the
  grey read poorly.

## 2026-09-14 - a Creality type is the material family (released in 1.49.0)

### Changed

- Benoit's call after reading the printer by hand: the frame's `type` is the
  material table's `material_type` for the chip's idMaterial ("PLA" for 24629
  "PLA High Speed"), falling back to the label when the table has none (four
  materials carry "" today). Carried like the other fields: `MaterialInfo`,
  the downloaded table, `TT_MATERIAL_INFO` (gen_db.py validates it against the
  UI font, since the printer echoes it back and the slot screen draws it), the
  resolver (`typeSrc`), the `[creality]` log line and `/api/resolve`. Vendor
  and name unchanged: the tag's brand and the endpoint's label, for now.

### Verified

- Host test: five type cases added (24629 -> PLA db, 38219 -> PLA db, 425
  ABS-CF -> ABS db, 51007 empty type -> label, unknown id -> label); all pass
  with the earlier ones.
- Ender-3 V4, the same R3D spool to 1D through the TigerSpool:
  `type=PLA(db) rfid=00001(api) temp=215/230(api) pa=0.04(db) name="Generic
  PLA"(api)`; read back type "PLA", vendor R3D, name, colour, pressure - and
  rfid "0", as expected with vendor R3D (the library match needs Generic).
  1D put back to its original values.

## 2026-09-14 - a filled material's type carries its filler (released in 1.49.1)

### Changed

- Benoit: Creality's type is `material_type`, plus "-" and `filled_type` when
  that is given - 425 ABS-CF is "ABS" + "CF" = "ABS-CF"; a null (or "", "-")
  filled_type adds nothing. `filledType` is carried beside `materialType`
  through `MaterialInfo`, the downloaded table, `TT_MATERIAL_INFO` (font-
  validated) and the resolver, which composes it.
- The rule reads `filled_type` only, not the `filled` flag, and the two
  disagree for eight materials today: PES, PETG-PTFE, PEI-9085, PAHT, PA11-GF,
  PETG-ESD and PLA-ESD are `filled: true` with no filled_type (sent as the bare
  family - PA11-GF as "PA"), and PC-PTFE is `filled: false` with filled_type
  "PTFE" (sent as "PC-PTFE"). Upstream data, for the TigerTag database.

### Verified

- Host test: 425 -> ABS-CF, 10738 -> PC-PTFE, 6605 -> PA, 38219 and 24629 ->
  PLA, a "-" filled_type -> no suffix; all earlier cases still pass.
- Device, downloaded table, `/api/resolve`: 425 ABS-CF (db) rfid 00004
  240/280; 38219 PLA; 24629 PLA; 10738 PC-PTFE; 6605 PA.
- Benoit corrected the source in Xano; `db_update.py` pulled it
  (filament_materials 1781878743554 -> 1789347116788). Changed: PA11-GF
  filled_type null -> "GF" (now "PA-GF"), PC-PTFE filled false -> true (type
  unchanged, "PC-PTFE"); density null -> 0 on PEI-9085, PAHT and PES, which the
  firmware does not read. Still `filled: true` without a filled_type: PES,
  PETG-PTFE, PEI-9085, PAHT, PETG-ESD, PLA-ESD. Header regenerated.

## 2026-09-14 - temperatures need a decimal point (released in 1.49.2)

### Fixed

- Benoit reported the TigerTag RFID Connect app's temperatures are kept by a
  Creality and the TigerSpool's are not. Slot 1C, written from his iPhone,
  read back minTemp 190 / maxTemp 240 with rfid "0" - so the printer DOES store
  per-slot temperatures, and the earlier conclusion in this file ("nothing on
  the printer holds them", "only the library profile") was wrong.
- The app's code (tigertag_connect1, creality_websocket_page.dart) builds the
  temperatures as Dart doubles, which jsonEncode writes as "190.0". The
  TigerSpool wrote integers. Sent straight to slot 1D from the Mac, the same
  frame otherwise: 215.0/230.0 -> read back 215/230; 216/231 -> 0/0;
  217.0/232.0 -> 217/232. The printer keeps a temperature only when the JSON
  number has a decimal point.
- `withPoint()` in backend_creality.cpp writes minTemp, maxTemp and pressure
  with one ("215.0", "0.04") and hands them to ArduinoJson as serialized text,
  since ArduinoJson writes the double 215.0 as "215".
- Tiger Studio has the same trap: PROTOCOL.md's table says float but its
  example writes 190, and renderer/printers/creality/index.js sends a JS number
  that JSON.stringify writes as 190. Not tested from Studio.

### Verified

- Ender-3 V4, the Duramic 3D PLA chip the iPhone wrote to 1C, through the
  TigerSpool to 1D: frame `"minTemp":190.0,"maxTemp":240.0`; read back 190/240,
  same as the app's write to 1C.

## 2026-09-14 - slot names in bold (released in 1.49.3)

### Changed

- screen_slots.cpp: the slot name above each colour block is font_ui_bold_16
  (Montserrat SemiBold), up from font_ui_12 regular - Benoit's request. 16 is
  the only bold size compiled in.

### Verified

- Bench: X1C (Ext., B1-B4) and Anycubic Kobra X (A1-A4) grids drawn in bold,
  nothing clipped. Not new, but a little closer now: the slot body does not
  scroll, and a printer with a third row of slots (a Bambu with two AMS, an
  Anycubic with more ACE units) already ran past the bottom of the panel.
- The brand under each slot, when it does not fit the 51 px cell, is cut
  with a single "." (`setFittedText()` in screen_slots.cpp, whole UTF-8
  characters, trailing space dropped before the dot) instead of LVGL's "...".
  Applies to every printer's slot screen. LV_LABEL_DOT_NUM left alone: it would
  change every truncated label in the product. Bench: "Duramic 3D" under the
  Ender-3's 1C and 1D reads "Durami.".

## 2026-09-14 - the Wi-Fi screen, redesigned (released in 1.50.0)

### Changed

- `screen_settings::showWifi()`: a network card (the header's wave via
  icons::wifiWave/setSignal, SSID in font_ui_bold_16, the level as a word in
  its colour - Excellent/Good OK green, Fair orange, Weak red, from the same
  -60/-70/-80 thresholds - with the dBm at 12 px beside it) and a details card
  (IP, MAC, channel at 14 px, dim name / white value). The wave, the word and
  the dBm update in place; the screen rebuilds only when the network, address,
  connection or channel changes. New parameter `channel`
  (WiFi.channel()); strings S_SIG_EXCELLENT/GOOD/FAIR/WEAK and S_CHANNEL in all
  eight languages. Previews `setwifi`, `setwifi-fair`, `setwifi-none`.

### Verified

- Bench: the three previews and the live screen (Stargate, Excellent,
  -47 dBm, channel 11) captured over /screen.bmp; nothing clipped.
- Details card rows (IP, MAC, channel) in font_ui_bold_16, name and value -
  Benoit's request. MAC fits with ~20 px to spare.
- The portal screens opened from Settings > Wi-Fi > Change network had no
  header and no exit. `screen_setup::showWifi()` / `showPortalReady()` take
  `withBack`; main.cpp passes it only when the portal was opened from Settings
  (`s_apFromSettings`), since a first boot has nowhere to go back to. Back
  calls the new `webcfg::endAP()` (captive DNS off, softAP down, STA mode),
  restores persistence and auto-reconnect that beginAP() turned off,
  `staBegin()` to rejoin the saved network, and returns to ST_SET_WIFI. The
  join screen's QR is 112 px instead of 132 and its spacing tighter under the
  header, or the password ran off the bottom. The setup header's chevron and
  title now match frame::build (white 24 px, bold title) on every titled setup
  screen. Previews `apwifi`, `apportal`.
- Verified: the three previews fit (captured). The back arrow itself is NOT
  verified from here: opening the portal takes the bench off the network the
  capture and tap API are reached over.
- A drawn padlock (icons::LOCK, added at the end of the enum so no existing
  value moves - FontAwesome's lock is not in the compiled symbol set) before
  the setup access point's password, on first boot and from Settings alike.
  Benoit's point: two accent lines under each other read as one name.
  Captured on the bench.

## 2026-09-15 - Chinese (released in 1.51.0)

### Added

- LANG_ZH, last in enum Lang so every stored index keeps its meaning (no
  LANG_SCHEMA bump - appending needs none). A ninth column on all 148 rows of
  the STR table; vocabulary aligned with the TigerScale's Chinese column
  (设置, 账户, 打印机, 耗材/料盘, 更新...). The NFC tester rows that are the
  same in every language stay English. NAMES: "中文". The Wi-Fi portal page
  gets a zh block and a "zh" language code; the four-column legacy page table
  still falls back to English for it, as it does for four other languages.
- The font, as the TigerScale does it: a subset of Noto Sans SC Medium
  (Sans2.004, OFL 1.1) holding only the characters the source uses, listed by
  the new scripts/cjk-chars.py (216 glyphs today), merged with --symbols into
  every regular and bold UI face by make-ui-font.sh - so no fallback chain is
  needed. Unlike the bold face the download is required: faces rebuilt without
  it would overwrite the committed ones, so the script exits 3 instead.
- gen-font-range.py records the subset in font_range.json ("symbols") and
  checks every face carries the same one; font_range.py adds it to the allowed
  set, so check-ui-fonts.py fails on a Chinese character the faces lack.
- Flash: 2 189 201 bytes, 52% of an OTA slot (was ~1.99 MB).
- README, firmware/README, installer page ("nine"), THIRD_PARTY_LICENSES,
  CLAUDE.md, CODEMAP updated.
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

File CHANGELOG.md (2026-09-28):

# Changelog

All notable changes to this project are documented here.

Format: [Keep a Changelog](https://keepachangelog.com/en/1.1.0/).
Versioning: [Semantic Versioning](https://semver.org/spec/v2.0.0.html).

## [Unreleased]

## [1.70.0] - 2026-09-28

### Changed

- **Reading a spool is more than twice as fast** - about 250 ms instead of 585.
  The chip's signature is still read and checked on every scan, never cached,
  but the ECDSA check runs in the background: the spool is sent, and the
  screen drawn, while it works.
- **The send result shows whether the spool is certified**, as the reader
  screen does - for brands that sign their spools, at the moment the spool is
  used.
- **A spool whose signature does not verify reads "Not certified"**, in plain
  grey, instead of a red "does not match".

### Added

- **A bench build** (`tigerspool-bench`) for diagnostics that must never ship:
  they sit inside `#if TIGERSPOOL_BENCH`, the release build does not compile
  them, and a check fails if one is left outside.

### Fixed

- **The screen no longer freezes for 1.5 s every thirty seconds.** The device
  reported itself to the account from the main loop - a TLS request that
  stopped the screen drawing and answering, in the middle of a scan or a send.
  It runs in the background now.

## [1.69.1] - 2026-09-28

### Fixed

- **A firmware update no longer stalls when the selected printer is an
  Anycubic in cloud mode.** The selected printer kept its connection during the
  download, and a cloud Anycubic's session beside it stalled the download at
  442 KB and left the device without a network until it restarted. A download
  now closes every printer connection, the selected one too, and the cloud
  session listens only for the slot reports it uses.

## [1.69.0] - 2026-09-28

### Added

- **Settings > Turn off.** The board has no power switch, so "off" is deep
  sleep with the panel dark and Wi-Fi down, and no button wakes it. Unplugging
  the USB cable and plugging it back in turns it on again, and the screen says
  so - with a battery fitted too, declared in Settings or not: the device then
  checks the battery pin every 3 s and boots when the charger lifts it (28 mV
  measured, full cell). In Settings it sits under Restart.

## [1.68.0] - 2026-09-27

### Added

- **Anycubic printers in cloud mode**, read and written. Tiger Studio writes
  the account's token and Anycubic's shared client certificate on the cloud
  printer's document; the device opens one session to Anycubic's broker for
  every cloud Anycubic on the account, and signs in as a web client so Tiger
  Studio and the slicer stay connected beside it. Proven on a Kobra X:
  connect, read and six writes. The first cloud Anycubic costs 50 load slots,
  each further one 4 - that second figure is not measured yet (#19).
- **The first printable case: a desktop stand** that fits beside any printer,
  with the spool on the left of the screen or on the right. Bambu Studio and
  Creality Print projects, every part on its own, and the Fusion source. The
  printable cases now live in `Model3D/`: the universal stand in `0.Desktop/`,
  then one directory per brand and one per printer model inside it
  ([Model3D/README.md](Model3D/README.md)).
- **Cases that clip onto the printer's screen**: the Creality K2 and K2 Pro,
  the Bambu Lab A1 and A2L, the FlashForge Creator 5 and Creator 5 Pro, and
  every Anycubic Kobra 3 - each a frame, a cover and a reader holder, with
  slicer projects and the Fusion source where there is one.
- **The README shows the device and where to print it**: the desktop stand as
  the base model, the printer integrations beside it, a MakerWorld link for
  every published model, the screens you tap through, every compatible
  printer with what to switch on first, and the FlashForge × TigerTag firmware
  that keeps Cloud and LAN on together on a Creator 5.

### Fixed

- **An Anycubic's grid no longer drops to one slot after a spool is sent.** The
  printer answers a set with a report carrying only the slot that was set, and
  the grid was rebuilt from it. LAN and cloud alike.

## [1.67.0] - 2026-09-23

### Added

- **The account page manages the account.** Signed in, the page the QR opens
  used to be one status line that refreshed onto itself: nothing on it signed
  out, and nothing anywhere synced. It now shows who is signed in - picture,
  name and address - signs out (after asking, since that restarts the
  device), and opens a drawer with every printer on the account: the same
  on/off switch the device's own list has, the same memory check behind it,
  and a button that syncs and redraws the list in place.

### Fixed

- **Signing in with an email no longer resets the device.** The web page ran
  the account sync itself, inside the request, on the main loop: a TLS
  handshake nested that deep overflowed the loop's stack the moment the
  sign-in succeeded, and the device rebooted with nothing saved. The sign-in,
  the Google pairing and the "Sync machines now" button now hand the sync to
  the task that already runs it on a timer. The page answers at once, and the
  screen stays usable for the ten seconds the sync takes - it used to hold
  still for all of them. Reported, with the decoded backtrace, in #15.

## [1.66.0] - 2026-09-21

### Changed

- **The battery is declared, not detected.** A box does not know whether a cell
  is on its connector: there is no sense line, the rail with an empty connector
  reads anywhere from 4.05 to 4.27 V depending on the board, and the charger's
  ripple - which a healthy cell damps - is not damped by a tired one. Both of
  our boards proved it, in opposite directions: one reported a battery it did
  not have, the other denied the pack it was running on, at 3.3 V, while
  running on it. So Settings now has a Battery row on every device, with one
  switch: yes or no. The level, the runtime and what the device tells the
  account all follow that answer.
- **Nothing that blocks starts in the half second after a touch.** Dialling a
  printer and beating to the account both open a TLS session on the main loop,
  and that loop is also what reads the back chevron: a handshake started the
  moment a finger lands is a press that appears to do nothing. Navigation comes
  first.

### Fixed

- **The screen could stop answering after a control redrew its own view.** A
  finger stays on the glass for ten reads or so; a screen rebuilt while it is
  down destroys the object LVGL believes is being pressed, and LVGL only clears
  that pointer for the deleted object itself, never for its children. Every
  later touch was then treated as a continuation of a press that no longer
  existed. Any screen rebuild now cancels the press in flight.
- **The printer list repainted the whole screen thirty to fifty times a
  second, doing nothing.** Two updaters ran on every pass of the loop and wrote
  what was already there: `lv_label_set_text` invalidates a label whatever it
  is handed, and `lv_obj_add_flag` invalidates an object when HIDDEN is in the
  mask even if it was already hidden. Both now write only on a change. Measured
  with `/screen.ver`: 29-55 frames a second at rest before, 0 after.
- `printer_ids` was always published empty, so Studio could not tell which
  printers a TigerSpool stands in front of. They were written to a single NVS
  key that the flash refused - 361 bytes, and this frozen 20 KB partition has
  no contiguous run that long left - and read back only when a sync reported a
  change. They are kept in RAM now, refreshed by every sync.

## [1.65.0] - 2026-09-21

### Changed

- The device document moved to `users/{uid}/tigerspools/{mac}` - plural, like
  every other collection of things under an account. 1.64.0 wrote the singular
  for one release and never created a document anywhere, because the account's
  rules refused every write, so there is nothing under the old name.

## [1.64.0] - 2026-09-21

### Added

- **The device declares itself to the TigerTag account.** It writes
  `users/{uid}/tigerspool/{mac}` every 30 seconds - every 5 minutes with the
  screen off, and at once when a spool is written or a cable moves - so Tiger
  Studio can list it, show whether it is online, and see which printers it
  stands in front of. The identity, liveness and battery fields carry the same
  names a TigerScale writes. See `docs/PRESENCE.md`.
- The pairing page now says what it is adopting: `TigerSpool`, with the real
  firmware version. It announced itself as a "TigerTag Bridge" running `cfs_ui`.

  **The account's security rules must name this path before any of it is
  allowed** - every beat is refused until they do, and the device holds off for
  five minutes after three refusals rather than retrying for ever. The rule is
  in `docs/PRESENCE.md`. Several TigerSpools on one account are supported by
  construction: one document each, keyed by MAC.

## [1.63.0] - 2026-09-20

### Fixed

- **Signing in with an email and password no longer restarts the device.** One
  route rebooted and the other did not, which is what a user reported. The
  restart was hiding a real gap: the loop only reloaded the printer list when
  it had asked for the sync itself, so a sync done from the web page landed in
  NVS with nobody reading it back. It reads it back now, and nothing reboots -
  not after an email sign-in, not after a Google one, not after a manual sync.

### Changed

- The Cancel button stays for the whole of the scan screen, including the write
  that follows the read. 1.62.0 took it away the instant the chip was caught,
  which turned out to be a flicker a fraction of a second before the screen
  changed anyway.
- The screen that waits for a chip no longer prints the reader's error in red
  under its own instruction. "Hold it closer" in red, under "hold the spool
  against the box", while somebody is doing exactly that, reads as a fault they
  have caused. The error still goes to the serial log.
- The reader is called **Scan** on the home screen and in its own header, and
  its second line asks the question it answers: "What is this?".
- In reader mode, a tap anywhere on the spool's data goes back, not only the
  chevron: the hand that is not holding the spool should not have to find a
  corner.
- Reader mode marks a valid chip **Certified** rather than "genuine",
  translated in each language.

## [1.62.0] - 2026-09-20

### Changed

- **The spool goes to the printer as soon as it is read.** The confirm step
  with its Send / No buttons is gone: choosing the slot and presenting the
  spool were the decision, and being asked a third time only stood between the
  user and the machine. Nothing new appears for the write itself either - the
  screen that asked for the spool stays exactly as it is, minus the Cancel
  button, which has nothing left to call off once the chip is caught. The
  write is over before a screen of its own could be read, and one that flashes
  past reads as a fault rather than as progress.
- The three screens of one send now share a title: the slot's name, alone.
  "Slot B2" on one and "B2" on the next read as two different places.
- **The screen after a send was rewritten.** One success screen instead of two:
  it confirms what was sent to the printer - the spool's colour, material,
  brand and diameter - and then names the next step in a green block, with the
  slot on its own line. It no longer shows what the slot held before, nor the
  colour the printer settled on. It stays five seconds, counted down by a bar
  that drains, and a tap anywhere ends it sooner.

### Added

- Reader mode shows the **drying** instruction the chip carries - temperature
  and hours on one line. The disc above it lost 8 px to make room, which is
  what a 320 px screen costs.

## [1.61.0] - 2026-09-19

### Added

- A home screen that asks what you came for: **Printers** or **Reader**. The
  printer list is one tap in, with a chevron back; the account and Wi-Fi state
  live on the home screen, which is where the device starts.
- **Reader mode**: put a spool on the pad and read it - colour, material,
  brand, finish, diameter, the two temperature windows, what is left on the
  spool, and whether the chip proved itself genuine. It is the NFC tester's
  question without the NFC tester's thirty fields, which stay in Settings.
- A **Write** row on the home screen, greyed and marked as coming: writing a
  spool from the device itself is not built yet, and the row says so rather
  than appearing one day and moving everything under it.

### Changed

- The account and Wi-Fi icons are on the home screen only. The printer list
  carries a back chevron, its title and the gear instead: 240 px does not hold
  all six, and the title was running under the icons.
- Settings returns to the screen the gear was pressed on.
- The reader row wears the same amber as the reader screen: one subject, one
  colour.
- Internal: a guard now fails the build when the device and the setup portal
  disagree about how many bars a signal is worth. The scale is written in two
  languages, in two files, and nothing but a person holding a phone beside the
  device would have noticed them drifting apart.

### Fixed

- Two NFC icons on one screen shared a single pixel buffer, so the second one
  drawn overwrote the first and both wore the second's colour. Each canvas icon
  now owns its buffer and frees it with the object.
- `scripts/flash.sh` no longer claims no board is plugged in when the
  PlatformIO virtualenv has lost its `esptool` module. It falls back to the
  copy that ships with the platform, and says so plainly if neither is there.

## [1.60.0] - 2026-09-18

### Changed

- **The Wi-Fi icon is calibrated for this radio, and it stops twitching.** The
  scale moved 10 dB: full strength is now -70 dBm rather than -60, so a network
  that works is no longer drawn as one that is failing - the ESP32 reads low,
  and by an amount that differs between boards, so the old scale worried people
  for nothing. The exact dBm is still printed beside the word. And the wave no
  longer moves every second when the signal wanders across a boundary: the
  reading is averaged once a second, and an arc is gained or lost only after
  3 dB past the line. A change of more than 15 dB is shown at once, because
  that is somebody moving the device rather than noise.

## [1.59.0] - 2026-09-18

### Fixed

- **An update could fail to install on a device with several printers.** The
  download opened its connection before the device had freed the memory a
  secure connection needs, and whether it succeeded came down to how much
  happened to be free: on a bench with seven printers linked it failed outright
  with 11 KB of contiguous memory where it needed 20. It now waits for the room
  - the printers step aside in a few milliseconds - and connects with 42 KB.
- **The screen woke but stopped answering.** After the display had gone to
  sleep once, taps did nothing at all: the sleep check and the drawing were
  both reading the touch panel, on the same bus, from two places.
- **The loading spinner on the first printer import is the right size and
  centred**, and says what it is waiting for. Padding on an LVGL arc is taken
  off the arc itself, so a 40 px spinner with 24 px of padding had 16 px left
  to draw in.

### Changed

- **The screen no longer freezes while the device talks to a printer.** Drawing
  and the touch panel now run on their own task, so a connection to a printer
  that is switched off - which blocks for over a second - no longer stops the
  interface. Measured on a bench with six printers: the panel went blind for
  7.9 seconds out of every 80, in gaps of up to 1.3 seconds; it is now 1.2
  seconds out of 80, and the worst gap is a tenth of a second. Scrolling stays
  smooth while a printer is being dialled, and a tap during it is no longer
  lost - it is acted on when the device comes back, instead of never.

## [1.58.0] - 2026-09-18

### Fixed

- **A device stuck on a distant access point now moves to the near one.** On a
  network with several access points sharing a name, the device chose once - at
  the moment it connected - and stayed there however bad the signal became. On
  the bench it sat on an access point at -73 dBm while another on the same
  network was at -48. It now checks once a minute and moves when another is
  clearly better. Moving costs a reconnection: the printers drop and come back
  within four to fifteen seconds, which is why it only moves for a large
  difference.
- **A spool write is never interrupted by the device changing access point.**
  Moving costs a reconnection, and one landing between Send and the printer's
  answer would turn a write into a failure the user watches happen. The device
  now stays where it is while a write is in flight and while a spool is being
  scanned, reviewed or sent.
- **A wrong Wi-Fi password is reported at once** instead of after a 30-second
  wait, and the log says why a connection was lost rather than only that it
  was.

## [1.57.0] - 2026-09-18

### Fixed

- **A board with no battery no longer shows a battery.** The charge is measured
  on a pin that reads the battery rail, and on USB that rail is held up by the
  charger whether a cell is plugged in or not - on one board at 4.27 V, on
  another at 4.01, which is where a real cell sits. A level alone cannot tell
  them apart, and the board has no pin to ask. The device now listens to the
  charger's own ripple instead: a cell swallows it, an empty connector does
  not. Measured on two boards, 2-3 mV against 7-22, and the answer takes a
  second.

## [1.56.0] - 2026-09-17

### Fixed

- **A Bambu AMS HT is now seen.** A printer reports its HT units as 128 and
  up, and everything above id 3 was being dropped: an X1C with two AMS and an
  AMS HT showed the two AMS and the external spool, and the dryer not at all.
  Reported with a full MQTT dump, which is what made it findable.
- **A Bambu with more than one AMS updates its slots in the background too.**
  The report from such a printer is about 9 KB and the background buffer held
  8, so it was dropped without a word - the slots only ever refreshed while
  that printer was the one on screen.

## [1.55.0] - 2026-09-17

### Fixed

- **The account stopped syncing on a device with many printers, and only the
  orange account icon said so.** The sync needs 16 KB of contiguous memory for
  its task; with seven printers linked the largest free block was 16 372 bytes
  - twelve short - and the mechanism that frees memory only ran once a sync had
  started, which this one never could. The room is now asked for before the
  attempt, and the log says how much memory there was when one fails.

### Changed

- Internal: the last Portuguese left in the firmware - status strings and
  comments in the printer backends - is now English, and the guard that checks
  for it knows the words it had been walking past.
- **The screen keeps moving while the printers are talked to.** Measured on a
  bench with six printers: the panel was blind for 8.9 seconds out of every 75
  - a Bambu report costs about 70 ms to read and they were all read back to
  back before the screen was allowed to draw. Three changes bring that to 7.9
  seconds and halve the typical gap: a read buffer in front of the MQTT socket,
  a frame drawn between printers rather than after all of them, and a loop that
  sleeps only as long as the interface says it can.

## [1.54.0] - 2026-09-17
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

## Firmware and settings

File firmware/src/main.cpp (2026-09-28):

// ============================================================================
//  TigerSpool RFID - main
//
//  Reads a TigerTag NFC chip and writes the filament into a printer slot.
//
//  State machine:
//    LANG -> WIFI -> (PROVISION) -> PRINTERS -> GRID -> SCAN -> REVIEW -> RESULT
//
//  Everything drawn lives in src/ui/ and is built from LVGL widgets. This file
//  owns the transitions and the data the screens read; it draws nothing itself.
//
//  Printers are imported from the user's TigerTag account into NVS namespace
//  "tigerspool" - they are never typed on this screen. See
//  docs/ARCHITECTURE.md and docs/ACCOUNT-DATA.md.
// ============================================================================
#include <Arduino.h>
#include <WiFi.h>
#include <WiFiClientSecure.h>
#include <esp_wifi.h>   // esp_wifi_set_bandwidth(), esp_wifi_set_country() - see staBegin()
#include <Preferences.h>
#include <nvs.h>
#include <LovyanGFX.hpp>
#include "LGFX_ESP32_S3_Touch_LCD_2.h"
#include "config.h"
#include "i18n.h"
#include "reader.h"
#include "battery.h"
#include "tt_db.h"
#include "printer.h"
#include "backend_creality.h"
#include "backend_ff.h"
#include "backend_bambu.h"
#include "backend_snapmaker.h"
#include "backend_elegoo.h"
#include "backend_anycubic.h"
#include "webcfg.h"
#include "net/ota.h"
#include "bambu_cloud.h"
#include "anycubic_cloud.h"
#include "bench.h"
#include <esp_sleep.h>
#include <driver/gpio.h>
#include "printer_budget.h"
#include "product_api.h"
#include <esp_task_wdt.h>
#include "imu.h"
#include "tigertag_cloud.h"
#include "ui/lvgl_port.h"
#include "ui/screen_home.h"
#include "ui/screen_setup.h"
#include "ui/screen_slots.h"
#include "ui/screen_scan.h"
#include "ui/screen_settings.h"
#include "ui/screen_read.h"
#include "version.h"

// ---- cores -------------------------------------------------------------
#define C_BG    0x0000
#define C_HDR   0x2104
#define C_TXT   0xFFFF
#define C_DIM   0x8410
#define C_SEL   0xFFE0
#define C_OKG   0x2606
#define C_ERR   0xF800
#define C_BTNR  0x9000
#define C_BTNG  0x0480
#define C_BTNB  0x1A4B

LGFX        lcd;
LGFX_Sprite canvas(&lcd);
bool        canvasReady = false;

Preferences nvs;
String  wifiSsid, wifiPass;
// Set from ARDUINO_EVENT_WIFI_STA_DISCONNECTED, reset to 0 (no reason codes
// use it) at the start of every staBegin() - see wifiReasonIsAuthFailure().
static volatile uint8_t wifiLastDisconnectReason = 0;
PrinterCfg printers[MAX_PRINTERS];
int     selectedPrinter = 0;
// Send was pressed on the review screen and is waiting, briefly, for the
// TigerTag+ product answer - see ST_SENDING.
static bool sendWaiting = false;

PrinterBackend* backend = nullptr;

// The printer link is held open, and held open is a state machine rather than
// a call. It used to be opened by selecting a printer and closed by leaving
// the slot screen: one view, no reconnection, and nothing anywhere else on the
// device could say whether the printer was reachable.
//
// Now: as soon as there is a network and a chosen printer, connect. Retry a
// bounded number of times, then STOP and say so - an indicator that spins for
// ever is one nobody believes, and a device that reconnects for ever to a
// printer that has been sold is one that never stops using the radio.
enum LinkState : uint8_t { LINK_IDLE, LINK_TRYING, LINK_UP, LINK_GAVE_UP };
LinkState linkState   = LINK_IDLE;
uint8_t   linkTries   = 0;
uint8_t   linkBudget  = 5;      // set from LINK_MAX_TRIES / LINK_RETRY_TRIES
uint32_t  linkStartAt = 0;
int       linkPrinter = -1;
// Five attempts, and long enough between them that a printer waking from
// standby gets a chance. A connect that has not landed in eight seconds is not
// about to.
static const uint8_t  LINK_MAX_TRIES = 5;
// A retry is asked for by someone standing in front of the box, watching a
// spinner. Five more attempts is forty seconds of that, which is long enough
// to walk away from. Three is twenty-four - long enough to be a real attempt,
// short enough to wait through.
static const uint8_t  LINK_RETRY_TRIES = 3;
static const uint32_t LINK_ATTEMPT_MS = 8000;
// How long a link that has run out of attempts waits before starting over.
static const uint32_t LINK_GIVEUP_RETRY_MS = 60000;
bool webStarted = false;
static void staNoSleep();          // defined beside LOOP_WDT_S
static void staBegin();            // likewise
static bool wifiReasonIsAuthFailure(uint8_t reason);   // likewise
static const char* wifiReasonStr(uint8_t reason);      // likewise

enum State { ST_LANG, ST_WIFI, ST_AP, ST_ACCOUNT, ST_MAIN, ST_READ, ST_SETTINGS, ST_PICK, ST_SET_WIFI, ST_SET_ACCOUNT, ST_SET_SCREEN,
             ST_SET_UPDATE, ST_SET_POWER_OFF, ST_SET_RESTART, ST_SET_FACTORY, ST_PRINTER, ST_GRID, ST_SCAN, ST_SENDING, ST_RESULT,
             ST_WEB_PAIR, ST_UPDATE_NOTICE, ST_SET_READER, ST_SET_BATTERY, ST_SYNCING, ST_CLOUD_SLOT, ST_CHOOSE_PRINTERS, ST_SET_READER_HEX };
State   state = ST_LANG;
// Which screen the gear was pressed on. Settings is reachable from both faces
// of the home screen, and coming out of it onto the other one moves the ground
// under somebody who only wanted to change the brightness.
State   settingsFrom = ST_MAIN;
// Whether the language screen was opened from Settings rather than reached on
// first boot. It decides two things: that the screen offers a way back, and
// where picking a language returns to. Inferring it from WiFi.isConnected()
// used to do both, and sent anyone whose network had dropped through first-boot
// setup again.
bool    langFromSettings = false;
bool    nfcReady = false;
uint32_t nfcLastTry = 0;
int     selSlot = -1;
TagInfo tag;
bool    sendOk = false;
String  resultMsg;
uint32_t stateSince = 0;

static int printerCount() {
    int n = 0;
    for (int i = 0; i < MAX_PRINTERS; i++) if (printers[i].type != PT_NONE) n++;
    return n;
}
static const char* typeTag(PrinterType t) {
    return t == PT_CREALITY ? "K2" : t == PT_FF_C5 ? "FF C5" : t == PT_BAMBU ? "Bambu"
         : t == PT_SNAPMAKER ? "Snap" : "--";
}

// ---- "is it online?" probe (TCP connect to the control port) ------------
// K2 = ws :9999 | FlashForge C5 = HTTP :8898 | Bambu = MQTT :8883
// Records when the last OK answer came in. A failed probe does NOT hide
// A single failed probe does not hide a printer: a TCP connect fails on a cold
// ARP cache or a congested link often enough that treating one miss as "gone"
// would make the list flicker.
static uint32_t pLastSeen[MAX_PRINTERS] = { 0 };
// The tag the NFC tester is showing, so the hex view can read the same one.
static const TagInfo* readerTag = nullptr;
static uint32_t pProbeAt = 0;
static int      pProbeIdx = 0;
static const uint32_t ONLINE_TTL_MS = 25000;   // stays "online" for 25 s without an answer

// The port the reachability probe knocks on, per brand.
//
// EVERY new backend must be added here, and the failure when it is not is
// silent and total: the probe knocks on the default - Creality's 9999 - gets
// nothing, marks the printer unreachable, and the link then refuses to dial a
// printer that is sitting there answering perfectly on its own port. Elegoo and
// Anycubic shipped in that state for exactly one release; a Centauri Carbon 2
// on the bench reported "probe says unreachable, not dialling" while Tiger
// Studio was talking to it.
static uint16_t ctrlPort(PrinterType t) {
    switch (t) {
        case PT_FF_C5:     return 8898;
        case PT_BAMBU:     return 8883;
        case PT_SNAPMAKER: return 7125;
        case PT_ELEGOO:    return 1883;
        case PT_ANYCUBIC:  return 9883;
        default:           return 9999;   // K2
    }
}
static bool probeOne(const PrinterCfg& p) {
    // A cloud printer has nothing on this network to knock on. Probing its
    // stale LAN address would mark it unreachable and hide it behind a failure
    // screen, when the truth is simply that it is somewhere else.
    if (p.type == PT_NONE || p.cloud || p.host.isEmpty()) return false;
    WiFiClient c;
    bool ok = c.connect(p.host.c_str(), ctrlPort(p.type), 900);
    c.stop();
    return ok;
}
static bool isOnline(int i) {
    return printers[i].type != PT_NONE && pLastSeen[i] != 0
        && (millis() - pLastSeen[i] < ONLINE_TTL_MS);
}
static int onlineCount();                   // fwd

// The reachability probe runs on its own task, and this is not a refinement -
// it is the difference between an interface that responds and one that does
// not.
//
// probeOne() is a synchronous TCP connect with a 900 ms timeout. Called from
// the main loop, as it was, a single switched-off printer froze everything for
// most of every second: measured at 600 to 1550 ms per pass on the home
// screen, which is the screen people spend their time on. Taps landed late,
// scrolling stuttered, and nothing on screen explained why.
//
// Nothing here needs to be in the loop. The probe produces one timestamp per
// printer and the loop only ever reads them; a 32-bit store is atomic on this
// core, so there is no lock to get wrong.
static TaskHandle_t pProbeTask = nullptr;
// Incremented once per printer probed. Until a printer has been LOOKED AT, the
// absence of a timestamp means nothing, and treating it as "offline" would stop
// the very first connection of every boot.
static volatile uint32_t pProbed[MAX_PRINTERS] = {0};
namespace disc { void sweep(); }   // defined below; the task drives it

static void probeTaskFn(void*) {
    for (;;) {
        // Slow right down when nothing answers at all - wrong network,
        // everything switched off. Otherwise the log fills with connect()
        // errors and hides anything useful.
        const uint32_t gap = (onlineCount() > 0) ? 1200 : 6000;

        if (WiFi.status() == WL_CONNECTED) {
            for (int k = 0; k < MAX_PRINTERS; k++) {
                int i = (pProbeIdx + k) % MAX_PRINTERS;
                if (printers[i].type == PT_NONE) continue;
                if (probeOne(printers[i])) pLastSeen[i] = millis() ? millis() : 1;
                pProbed[i]++;
                pProbeIdx = (i + 1) % MAX_PRINTERS;
                break;
            }
        }
        disc::sweep();   // the other blocking network job, off the loop for the
                         // same reason: 254 connects at 150 ms apiece.
        vTaskDelay(pdMS_TO_TICKS(gap));
    }
}

static void startProbeTask() {
    if (pProbeTask) return;
    // 4 KB: a socket, a connect, nothing else. Core 0, because the Arduino
    // loop and LVGL have core 1 and the whole point is to stay off it.
    xTaskCreatePinnedToCore(probeTaskFn, "probe", 4096, nullptr, 1, &pProbeTask, 0);
}

static int onlineCount() {
    int n = 0;
    for (int i = 0; i < MAX_PRINTERS; i++) if (isOnline(i)) n++;
    return n;
}
// Configured printers are ALWAYS listed. Reachability is an indicator, not a
// filter: the TCP probe is not reliable enough to hide anything, and a printer
// anything: a K2 or FlashForge with LAN Mode off answers RST on that port.
static bool printerVisible(int i) {
    return printers[i].type != PT_NONE && printers[i].visible;
}
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
void loop() {
    // Joined on the FIRST pass, not in setup(): setup() waits on Wi-Fi at
    // boot, which is slow on a weak link and entirely legitimate, and a
    // watchdog that fired there would turn a slow start into a boot loop.
    static bool watched = false;
    if (!watched) { esp_task_wdt_add(nullptr); watched = true; }
    esp_task_wdt_reset();                    // one feed per pass - see LOOP_WDT_S
    BENCH_BEGIN();

    // The config page belongs to the network, not to a screen: as soon as there
    // is an address, http://tigerspool.local answers. That also means the setup
    // screens are reachable for a remote screenshot, which is how this UI gets
    // checked without someone standing in front of the device.
    if (!webStarted && WiFi.status() == WL_CONNECTED) onWifiUp();

    // Wi-Fi is dialled once at boot and never again - until now.
    //
    // If the association fails at startup, or the access point drops it later,
    // the device sits there for ever with a lit screen, every printer red and
    // no route to the account: watched happening twice today, once at boot and
    // once mid-session, on a link measured at -80 dBm where the radio is at the
    // edge of what it can hold. Arduino's own auto-reconnect did not bring it
    // back either time.
    //
    // So: after fifteen seconds down, ask again, and keep asking every thirty.
    // A device left alone on a bad afternoon has to end up connected, because
    // nobody is going to power-cycle it.
    if (!wifiSsid.isEmpty() && state != ST_AP && state != ST_WIFI) {
        static uint32_t downSince = 0, lastRetry = 0;
        if (WiFi.status() == WL_CONNECTED) { downSince = 0; lastRetry = 0; }
        else {
            const uint32_t now = millis();
            if (!downSince) downSince = now ? now : 1;
            else if (now - downSince > 15000 && now - lastRetry > 30000) {
                lastRetry = now;
                Serial.printf("[wifi] down for %lus - associating to '%s' again (%s)\n",
                              (unsigned long)((now - downSince) / 1000),
                              wifiSsid.c_str(), wifiReasonStr(wifiLastDisconnectReason));
                staBegin();
            }
        }
        roamCheck();
    }

    // The backlight is the only thing that sleeps. Everything below this line
    // keeps running whether the screen is lit or not.
    // Follow the accelerometer, but only when the user asked for it and only
    // on a reading the sensor is sure of. Checked once a second: turning a box
    // over is not a gesture that needs millisecond response, and polling an
    // I2C sensor the touch panel shares is not free.
    if (screenAutoRot) {
        static uint32_t lastLook = 0;
        if (millis() - lastLook > 1000) {
            lastLook = millis();
            int want = imu::suggestedRotation();
            if (want >= 0 && want != screenRotation) {
                screenRotation = want;
                lvgl_port::setRotation(want);
                nvs.begin("tigerspool", false);
                nvs.putInt("rot", want);
                nvs.end();
            }
        }
    }

    // The screen never sleeps during setup. Every one of these states puts
    // something on the panel that has to be READ off it - a QR code to scan, a
    // pairing code to type, a network being joined - and a screen that goes
    // dark while someone is holding a phone up to it is a screen that has
    // failed at its one job. The sleep timeout is for the home screen, where
    // the device sits idle between spools.
    const bool inSetup = (state == ST_LANG || state == ST_WIFI || state == ST_AP
                       || state == ST_ACCOUNT || state == ST_WEB_PAIR);
    lvgl_port::sleepTick(inSetup ? 0 : screenSleepSec, screenBrightness);
    BENCH_MARK("wifi+imu+sleep");

    // A heartbeat for the heap, every thirty seconds.
    //
    // Links open and close over hours, and each cycle builds and destroys a
    // backend. Whether that returns everything it took cannot be seen from a
    // single reading - only from the trend - and the device has already been
    // found at two kilobytes free with its network stack unable to open a
    // socket while it still believed it was on Wi-Fi. This line is what makes
    // the difference between a leak and a busy afternoon visible.
    {
        static uint32_t lastHeapLog = 0;
        if (millis() - lastHeapLog > 30000) {
            lastHeapLog = millis();
            int live = 0;
            for (int i = 0; i < MAX_LINKS; i++) if (links[i].state == LINK_UP) live++;
            // PSRAM alongside the internal heap, because the two answer
            // different questions. Internal RAM is what a socket, a TLS session
            // and an MQTT buffer come out of, and it is the one that runs out.
            // The 8 MB of PSRAM is almost untouched - LVGL's heap lives there
            // and nothing else does - so knowing how much of it is idle is how
            // anyone decides whether moving a buffer there is worth the work.
            Serial.printf("[heap] %u free, %u largest, psram %u/%u free, "
                          "%d link(s) up, wifi=%d rssi=%d\n",
                          (unsigned)ESP.getFreeHeap(), (unsigned)ESP.getMaxAllocHeap(),
                          (unsigned)ESP.getFreePsram(), (unsigned)ESP.getPsramSize(),
                          live, (int)WiFi.isConnected(), (int)WiFi.RSSI());
            // On the same half-minute, and on one line, so a board that has
            // been running for an hour can be read back rather than watched.
            Serial.printf("[batt] %d mV at the pin, %.2f V at the cell, %d%%%s\n",
                          battery::millivolts(), battery::volts(),
                          battery::percent(),
                          battery::present() ? "" : " (no battery)");
        }
    }

    // The account is kept fresh from here rather than from one screen, so the
    // freshness the header reports is a fact about the network and not about
    // where the user happens to be standing.
    if (!s_memtest && ttcloud::due() && !ttcloud::asyncBusy()) ttcloud::startAsyncSync();
    BENCH_MARK("sync-start");
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

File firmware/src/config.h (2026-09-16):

#pragma once
#include <Arduino.h>

// ---- PN532 over HSU / UART1 (free pins; GPIO6/7 is I2C with pull-ups) -----
#define PN532_UART_NUM   1
#define PN532_UART_RX    44      // ESP32 RX  <- PN532 TXD
#define PN532_UART_TX    43      // ESP32 TX  -> PN532 RXD
#define PN532_UART_BAUD  115200

// ---- Battery -----------------------------------------------------------
// The board's battery sits behind a divider on this pin. GPIO5 is what the
// Waveshare schematic and MicroPythonOS both use for the ESP32-S3-Touch-LCD-2,
// and it is measured against a multimeter before it is believed - see
// battery.cpp. Nothing else on this device uses GPIO5.
#define BATTERY_ADC_PIN  5
// The divider ratio: what the pin reads, times this, is the cell. The board's
// schematic puts 200K over 100K there, so the pin sees a third of the battery.
// Checked on two boards: one with a cell read 1324 mV (3.97 V), one without
// read 1424 mV, which is the charger's own output with nothing to charge.
#define BATTERY_DIVIDER  3.0f

// ---- Panel -------------------------------------------------------------
#define SCR_W  240
#define SCR_H  320
#define SCR_ROTATION  2          // portrait, rotated 180

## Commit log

2026-09-02 Bootstrap the TigerSpool RFID repository
    Documentation, structure and decisions. No firmware yet — the bench
    prototype has not been migrated, and nothing here builds or runs.
    What this establishes:
    - The product and its positioning: printers are added once in Tiger
    Studio and arrive on the device by themselves. That is the whole
    differentiator and it is the first thing the README says.
    - The target firmware architecture — layers, state machine, and a
    printer backend abstraction that already held across four protocols
    in the prototype without changing.
    - Every hardware fact the prototype paid for, written down with the
    failure mode it prevents. The reader is on GPIO43/44; GPIO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
2026-09-02 Resolve the pairing and OTA-signing questions from TigerScale V3's code
    Both were answered by reading the shipped firmware rather than the
    documentation, and both times the code says something different.
    Pairing endpoints. TigerScale V3 hardcodes the same two Cloud Functions
    the prototype calls — .../pairStart and .../pairPoll. The
    /api/device/pair/* path described in V3's own ACCOUNT-PAIRING.md is not
    called anywhere in its firmware. TigerSpool codes against the deployed
    Cloud Functions; migrating later is a two-constant change. The TODO in
    docs/ACCOUNT-PAIRING.md is resolved.
    OTA signing. There is no TigerTag signing key to reuse: no public key
    compiled in, no signing step in the relea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
2026-09-02 Elegoo and Anycubic are a port, not a reverse-engineering exercise
    Both protocols are already documented and working in Tiger Studio, from
    live captures of the vendors' own slicers against real printers:
    renderer/printers/{elegoo,anycubic}/PROTOCOL.md.
    Elegoo is MQTT over plain TCP on 1883 — simpler than Bambu Lab, no TLS
    at all — with numbered methods for reading and writing a slot and a
    captured 50-entry filament_code table. Anycubic is MQTT/TLS on 9883 with
    getInfo/setInfo on a multiColorBox topic, an [r,g,b] colour array, and a
    fixed list of accepted material names.
    Two things carry real risk and are recorded as such. Anycubic's broker
    insists on TLS 1.2 and requests an optional cl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
2026-09-02 Document the account data model, from a real account's schema
    The account carries far more than a list of addresses, and two things in
    it change the firmware design.
    It already holds a normalised, brand-agnostic slot model. Every brand's
    document exposes units[] -> slots[] with material, colour, vendor and a
    `hw` object carrying that printer's own addressing: {extruder} for
    Snapmaker, {canvasId,trayId} for Elegoo, {slot} for FlashForge,
    {boxId,slotIndex} for Anycubic. That is exactly the split PrinterBackend
    makes — a flat list for the UI, real addressing inside the backend. The
    firmware and Tiger Studio reached it independently, so the two can be
    aligned rather than merely made compatibl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
2026-09-02 Separate Anycubic LAN and cloud in the compatibility matrix
    A real account shows an Anycubic printer in cloud mode: no ip, no broker
    credentials, only a cloud printer id, a key and an expiring token. Such a
    printer opens no local ports at all, so the LAN path cannot reach it —
    the only route is Anycubic's own service, with signed REST and a second
    MQTT broker.
    These are two implementations, not one with a flag, and whether v1 ships
    both is not decided. The matrix now lists them as separate rows rather
    than letting a cloud printer look supported because a LAN one is. The
    same open question already applies to Bambu Lab.
2026-09-02 Record what a hardware session actually proved
    A full scan-to-printer loop was exercised on a board, and three of the
    findings are worth more than the assumptions they replace.
    The loop works end to end on a FlashForge AD5X — a model the prototype's
    backend was never written for; it targets the Creator 5 Pro and speaks
    the same msConfig_cmd API. The assignment was confirmed by re-reading the
    printer's slot state rather than by trusting its acknowledgement, which
    matters on an API that answers code:0 to commands it ignores. The AD5X
    joins the compatibility matrix as verified.
    Fidelity loss is real and invisible to the user. A tag reading
    "PLA High Speed, R3D, #DC123F" landed on the printe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
2026-09-03 First-boot journey in LVGL, and eight languages with their accents
    Language, then Wi-Fi, then the account - the order matters, because every
    message in the last two is written in the language chosen in the first.
    i18n is rebuilt around English as index 0 and fallback, with eight
    locales matching TigerScale. Accents are written normally: the
    prototype's font was ASCII-only, so every language had been stripped of
    its diacritics. Chinese is deliberately absent rather than rendered as
    empty boxes - it needs a generated CJK subset font, and offering a
    language that does not draw is worse than not offering it.
    That renumbering surfaced a bug worth keeping the guard for. The
    prototype ordered its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
    [main.cpp]
2026-09-03 Every screen is LVGL, and the raw drawing is gone
    The slot grid, the scan, the confirmation and the result now build from
    LVGL widgets like the home and setup screens, and main.cpp draws nothing
    at all: 231 lines of pixel-coordinate drawing, the hand-rolled touch
    handling and the pagination state are deleted rather than left beside
    their replacements.
    What the port buys, beyond consistency:
    - The grid scrolls. Six slots per page was already wrong for a Bambu X1
    reporting seventeen trays and worse for an Anycubic Kobra X reporting
    twenty, and the page arrows were a 2 mm target for moving past a 12 mm
    one. LVGL's scroll container also brings the "a press that moved is not
    a tap" rule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
    [backend_bambu.cpp, backend_ff.cpp, main.cpp]
2026-09-03 Give the device a name of its own, and a setup portal worth opening
    Two devices could not coexist. mDNS refuses a duplicate, so a second
    TigerSpool never claimed tigerspool.local and became unreachable by name
    - and worse, two devices in setup mode both broadcast TigerSpool-Setup,
    so a phone joins one at random and its owner configures the wrong box
    without ever knowing. Both names now carry the last four hex digits of
    the station MAC: tigerspool-9918.local and TigerSpool-Setup-9918,
    verified on hardware. The suffix costs nothing, because the QR on the
    screen carries the SSID and nobody types it.
    The station MAC, not the access point's - they differ by one on an
    ESP32, and that distinction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
2026-09-03 Wire the account step, and ask which way in
    The device sat on the Wi-Fi setup screen after the portal had already
    joined the network. ST_AP returned every loop without ever checking the
    connection, so nothing advanced it - a direct consequence of removing the
    reboot: ESP.restart() used to be what moved the screen on, and taking it
    out left nothing in its place.
    The account step now exists. An unlinked device goes there instead of to
    an empty printer list, and it asks HOW to log in before showing anything:
    an account made with Google has no password to type, one made with an
    email has no Google to fall back on, and the device cannot tell them
    apart. Guessing sends half of all users to a scre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
    [lvgl_port.cpp, main.cpp, tigertag_cloud.cpp]
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2026-09-03 Settings, a printer picker, and a home screen that stopped rebuilding itself
    The printer list rebuilt on every pass of the main loop - sixty times a
    second, tearing down each row under the finger pressing it. Taps never
    landed and the CPU did nothing else, so the device looked frozen while it
    was perfectly healthy. It rebuilds on a content hash now, the same guard
    the slot grid already had and this screen never got.
    Settings exists. Eight entries, each showing its current value on the
    right so the list answers "what is it set to" without opening anything.
    Printers, Language and Restart are wired; the rest are listed because a
    row that does nothing is better than a row that is missing and
    un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
    [main.cpp]
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2026-09-04 Name the slots the way the printers and Tiger Studio name them
    A slot name is what a user reads on the box and matches against the
    machine in front of them. Four of them were ours rather than the
    printer's.
    Snapmaker was A/B/C/D and is E1-E4, one per extruder. FlashForge was
    T1-T4, which is not wrong but is something else entirely - those are the
    Creator 5 Pro's tool-changer nozzles; the material station this backend
    drives is 1A-1D. Bambu was A/B/C/D, and its multi-unit path built 1A/2A,
    which is Creality's scheme on a Bambu; it is A1-A4 for the first AMS and
    B1-B4 for the second.
    The external slot was the Portuguese literal "Suporte", drawn on the
    panel. S_HOLDER already existed in the t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
    [backend_bambu.cpp, backend_ff.cpp, backend_snapmaker.cpp]
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2026-09-04 The language screen had no way out when opened from Settings
    Opening Settings and tapping Language to see which one was set left you
    with no exit: the only way off that screen was to pick a language,
    including for someone who had opened it to look. Both halves of the fix
    already existed - showLanguage takes a withBack flag and takeBack()
    reports the chevron - and the state machine simply never passed or read
    them.
    Which caller it came from is now a flag rather than an inference. It
    decided the return path by testing WiFi.isConnected(), so anyone whose
    network had dropped while they were in Settings would have been sent back
    through first-boot setup after changing a language.
    The title foll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
    [main.cpp]
2026-09-04 Over-the-air update on the device
    The two OTA slots have been in partitions.csv since the firmware import,
    with nothing to put in them. This is the device half: fetch the published
    manifest, compare versions, stream the image into the spare slot, verify
    it, and restart into it.
    Ported from the sibling project's proven implementation, with its
    hard-won details kept because they were paid for once already. The image
    is hashed while it is written rather than afterwards, so no second pass
    over 1.4 MB. The stall timeout is thirty seconds, not ten: a TLS record
    genuinely gaps for longer than ten on a busy device, and the abort looked
    like a network fault when it was impatience. Both the free heap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
    [lvgl_port.cpp, main.cpp, ota.cpp]
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2026-09-04 The sign-in QR led to the Wi-Fi picker
    Reported by a user, and correct. The QR on the e-mail sign-in screen
    carried the device's root URL, and "/" serves the configuration page:
    that page opens with the network selector and puts the account form some
    forty lines below it. A phone scanning a QR to sign in landed on a Wi-Fi
    list and had to scroll to find what it came for.
    Worse than confusing. The first control under the finger was a save-and-
    restart for the network settings, on a device that had just joined a
    network and was showing its address on that network.
    The QR now points at /login, a page with one job: the e-mail and password
    form, and the Google button. Same POST handler as before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
    [i18n.js, main.cpp]
2026-09-04 The shopping list only lists things you buy
    The jumper wires and the printed case were rows in it. Neither is
    purchased: the wires come in the PN532's box and the case comes off your
    own printer. A shopping list that includes things you already have makes
    the reader check whether they missed something.
    Three rows now, which is the true count.
    Forty-five dead translation entries went with them, across nine
    languages. An unused string is weight nothing checks, and this file has
    no guard for it.
    Where the wires and the case belong is the bill of materials, which
    already says the wires are supplied and the case is printed.
    [i18n.js]
2026-09-04 A boot screen, drawn at the first instant the panel can show anything
    lcd.pushImage straight from flash, immediately after lcd.init() and
    before LVGL exists. Everything after that line - LVGL starting, the
    language table, the NVS read, the reader handshake - now happens with the
    logo already up, instead of behind a black screen.
    No timer holds it. It stays until the first real screen replaces it, so
    the device is never slower than it needs to be in order to look
    considered.
    scripts/make-rgb565-header.py converts the PNG, using only the standard
    library so CI can re-run it. It refuses to resize: which crop, which
    interpolation, whether the logo still reads at that size are design
    decisions,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
    [main.cpp]
2026-09-04 Hold the boot screen for a second, and make it inspectable
    Reported as "it does not fill the space". It does: captured through the
    new preview, the bitmap covers all 240x320 and is identical to the
    source. What was actually happening is that the device boots faster than
    the eye reads, so LVGL began repainting over the logo before it had been
    seen - which looks exactly like a picture that does not fit.
    So it is held for a second, and the second is not wasted. The deadline is
    set where the image is drawn and only waited out at the end of setup(),
    so LVGL starting, the language table, the NVS read and the reader
    handshake all happen inside it. A board that takes longer than a second
    to come up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
    [lvgl_port.cpp, main.cpp]
2026-09-04 The update page checks when you open it, and says so in one glance
    Opening the update page and then being asked to press "Check for update" made
    the user state an intent they had already stated by arriving. The check now
    runs on entry; the button stays for the two cases that still need it, no Wi-Fi
    and retrying after a failure.
    The screen was also reporting in the wrong shapes. A percentage bar became a
    152 px ring with the number inside it, taking the whole screen while the image
    is written - no header and no way out, because the download runs on its own
    task and leaving would only hide it. The installed version became a settings
    row rather than a headline, and the answer the user came for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
    [main.cpp]
2026-09-04 Orange means interrupted, red means destroyed, and a waiting update says so
    Read straight off a TigerScale over its live view rather than from memory, and
    aligned where the two devices are talking about the same thing.
    Everything consequential was red, so red had stopped meaning anything. It now
    means the action destroys state the device cannot rebuild - a factory reset.
    Orange means it interrupts what is on screen and destroys nothing: restarting,
    and an update waiting to be installed. That last one is the only announcement
    an available update gets outside its own page; the device checks once, twenty
    seconds after boot, and never on a timer afterwards. A spool reader is not a
    phone.
    The u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
    [main.cpp]
2026-09-04 Every settings row says what it is before it is opened
    The TigerScale puts a 26 px icon at the left of every settings row and keeps
    the label white, so the row's state lives in one glyph: green for something
    reachable, red for something that is not, orange for what interrupts, red for
    what destroys. Read off a live scale, not from memory. This does the same.
    Wi-Fi is green once joined and red offline, the account likewise, printers red
    while the account has none - which is the single most common thing wrong with a
    new device and previously had to be discovered by opening the row. Restart is
    orange, factory reset red, and an update waiting to be installed turns its own
    row orange.
    Only the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
    [main.cpp]
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2026-09-05 Orientation, outlined rows, the account's name, and a live view you can click
    Four changes to the same surface, kept together because they were built and
    verified against each other on the panel; each is named below so a reviewer can
    take them one at a time.
    **Orientation is the user's, not the build's.** SCR_ROTATION was compiled in,
    and both mountings of this board exist - a device in the other shell came up
    upside down with nothing on screen to fix it. It now sits under Display beside
    brightness and sleep, is applied the moment it is chosen, and survives a
    reboot. It is applied again after lvgl_port::begin() at startup, because the
    boot logo is drawn before the stored value is read and a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
    [lvgl_port.cpp, main.cpp]
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2026-09-05 The setup QR appears when you ask for it, not four seconds later
    Picking a language on a new device was followed by several seconds of a screen
    that did not move, and a screen that does not move reads as a device that has
    crashed, not one that is working.
    Two causes, and both were work queued in front of the thing the user was
    waiting for.
    beginAP() ran a full Wi-Fi scan on its way up, synchronously. A scan takes
    seconds. Nothing needed that list yet - the portal fetches it when someone
    opens the portal, which is the only place it is used - so the whole of setup
    was blocked behind a list nobody had asked for. It is gone from that path;
    doScan() is still what /?rescan=1 calls.
    And the QR w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
    [main.cpp]
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2026-09-05 Sign in by scanning the box, and the box shows what it is waiting for
    Following the sign-in page, the Google pairing step. It was the last screen
    still wearing the prototype's styling: centred text, a raw blue link, and an
    instruction to "open this link on a phone or PC" - advice to someone who had
    already done it, and equally wrong for someone reading the page at a desk after
    typing the address off the device's screen. A page cannot know which, so it no
    longer guesses.
    It now leads with the thing that works from anywhere: scan the QR on the
    TigerSpool's screen. Then the code, then "or", then Continue with Google for a
    browser already signed in. And the device holds up its end - for as long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
    [main.cpp]
2026-09-05 The setup access point is encrypted, and that is what Android was refusing
    A Galaxy S24 joined the setup network and never showed the captive-portal
    sheet. The reporter found the cause: Android does not treat an open network
    with no internet as a destination, it treats it as a mistake to correct -
    Samsung's adaptive Wi-Fi drops back to mobile data rather than probing for a
    portal. An encrypted network is handled as somewhere the user chose to be.
    iPhones were unaffected, which is exactly why this looked like a timing problem
    for as long as it did.
    Nothing is typed. The Wi-Fi QR format carries a key, so the phone still joins
    in one tap. docs/WIFI-PROVISIONING.md argued for leaving the AP ope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
    [main.cpp]
2026-09-05 The captive portal's DNS was answering a different question than it was asked
    Third attempt at this, and the first one that was tested before being claimed.
    The core's DNSServer writes an answer of type A whatever type was asked for.
    replyWithIP() hardcodes answerType = DNS_TYPE_A, so a query for an AAAA record
    comes back with a question section saying AAAA and an answer section holding
    four bytes of IPv4. That is not a valid response, and a resolver is entitled to
    throw it away.
    Android asks for A and AAAA in parallel and waits for both. The A answer
    arrived. The AAAA answer was discarded as malformed, so that half of the lookup
    sat there until it timed out - past the deadline of Android'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
    [main.cpp]
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2026-09-05 Print the Wi-Fi signal, because a colour is not something anyone can act on
    The home screen colours its Wi-Fi glyph by strength - green above -60 dBm,
    yellow to -75, orange below - and someone looking at an orange icon has been
    told there is a problem and nothing about what to do. A number says whether to
    move the box or move the router.
    It also settles the question it was added to answer. The bench unit shows
    orange while a scan sees that same network's beacon at -55 dBm, which looks
    like a contradiction and is not: a scan measures the strongest beacon in
    earshot, RSSI measures the association actually in use. The device is on -78,
    which is genuinely weak - about where a Bambu's MQTT start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
    [main.cpp]
2026-09-05 Delete the prototype's configuration form, and the bug it was hiding
    Reported from the bench: joined the setup access point, the captive portal
    opened, and it showed the prototype's old configuration page - the one with a
    network dropdown and four printers to type in by hand.
    The route table was built twice. Once when the device came up on the network,
    once when the access point started. The ESP32 web server keeps its handlers in
    a list where the FIRST match wins, so the second registration of "/" was dead
    and "/" still pointed at whatever the device had been doing when it first
    booted. Registered once now, and "/" decides on apMode inside the handler,
    where it cannot go stale. handleCaptiv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
    [main.cpp]
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2026-09-14 What a Creality slot is sent, and from where
    A Creality slot was sent rfid "0", the chip's temperatures or 190/230 and the
    material label as its name. Every value is now resolved field by field -
    TigerTag+ product endpoint, chip, material table, default - by a pure
    resolver tested off the device, and sent in the TigerTag Connect app's frame:
    Creality material id, temperatures, pressure advance, the material family as
    type. The endpoint is asked on a task when a TigerTag+ is read, within a 3 s
    budget; the material table keeps the Creality fields, compiled in too, so an
    offline device still resolves them. The slot screen's names and brands are
    white.
    [filament_resolve.h, main.cpp, product_api.cpp]
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2026-09-17 Wi-Fi: proactive roaming, reason-aware retry, RF tuning (#9)
    staBegin() chose an access point once, at connect time, and never asked again while the link stayed technically up. roamCheck() now scans once a minute while connected and reassociates when another AP on the same SSID beats the current one by 8 dB or more. Reproduced on the bench before the change: the device sat on an access point at -73 dBm while another on the same network was at -48.
    Moving costs a reconnection - every printer link drops and comes back within four to fifteen seconds, measured - which is why the hysteresis is wide.
    The disconnect reason is now tracked, so a wrong password fails at once instead of waiting out t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
    [main.cpp]
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2026-09-26 Add the desktop stand; printable cases move to Model3D/
    The first case: a free-standing stand, spool on the left of the screen or
    on the right, as Bambu Studio and Creality Print projects, bare parts and
    the Fusion source, with previews taken from the projects.
    Model3D/ replaces models/: 0.Desktop for the universal stand, then one
    numbered directory per brand and one per printer model inside it, a
    TEMPLATE.md for model READMEs. scripts/clean-3mf.py cuts import paths
    and the Bambu account number out of a 3MF and lists object names for
    review; scripts/check-models.py, run by verify.sh, enforces the layout,
    names without spaces and 3MFs without paths.
    [tigerspool-desk-left-base.3mf, tigerspool-desk-left-display-cover.3mf, tigerspool-desk-left-display.3mf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]
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2026-09-28 Release 1.69.1: an update no longer stalls beside a cloud Anycubic
    [anycubic_cloud.cpp, main.cpp]
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

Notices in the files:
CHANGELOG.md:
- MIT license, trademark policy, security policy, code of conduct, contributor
